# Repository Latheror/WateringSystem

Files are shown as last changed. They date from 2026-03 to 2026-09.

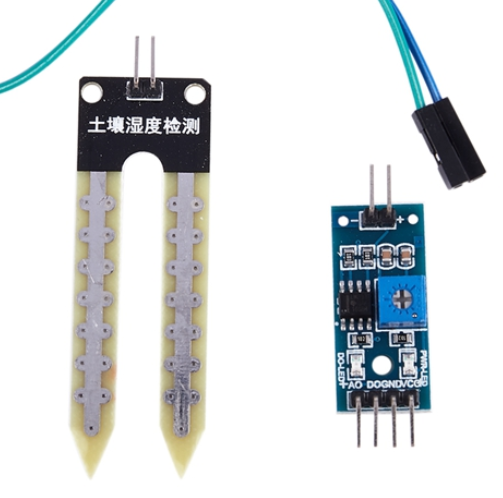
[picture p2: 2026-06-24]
Hardware/HygrometrySensor/HygrometrySensor.png

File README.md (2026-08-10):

# Watering System Project

## Overview
This project is an automated watering system for plants, featuring soil moisture monitoring, solar power management, and manual/automatic watering controls.

## Features
- **Soil Moisture Monitoring**: Real-time monitoring of soil moisture using both analog and digital sensors.
- **Automatic Watering**: Automatically activates the pump when soil moisture levels fall below a certain threshold.
- **Manual Watering**: Allows users to manually trigger a 10-second watering cycle via a web dashboard.
- **Power Management**: Monitors solar panel voltage and battery levels.
- **Web Dashboard**: A responsive web interface to view system status and control watering.

## Development Guidelines & Best Practices

### 1. Code Structure & Organization
- **Modularity**: Keep logic separated into different files (e.g., `wifi_handler.cpp`, `settings.h`).
- **Constants**: Use `settings.h` and `settings_user.h` for all hardware-specific configurations (pins, thresholds, WiFi credentials).
- **Non-blocking Code**: Avoid using `delay()` in the main loop where possible. Use `millis()` for timing-based operations (e.g., watering duration).

### 2. Hardware Abstraction
- **Relay Control**: Abstract relay operations to ensure consistent behavior (e.g., handling active-high vs. active-low modules).
- **Sensor Reading**: Standardize how sensors are read and processed before being used in logic.

### 3. Error Handling & Logging
- **Serial Debugging**: Use `Serial.println()` for critical state changes and errors.
- **Robustness**: Ensure the system can recover from WiFi disconnections or sensor failures.

### 4. Embedded C Best Practices
- **Memory Management**: Avoid dynamic memory allocation (`malloc`, `new`) to prevent memory fragmentation and leaks.
- **Data Types**: Use appropriate fixed-width integer types (e.g., `uint8_t`, `int32_t`) from `<stdint.h>`.
- **Naming Conventions**: Use clear, descriptive names for variables and functions.

## Project Structure
- `Board/`: Hardware design files.
- `Case/`: 3D model files for the enclosure.
- `Hardware/`: Component details and wiring diagrams.
- `system/`: Source code for the ESP32C3 microcontroller.

## PCB

The KiCad design files for the watering system are located in `PCB/`. These files are read and edited with KiCad 10.

### Design files

- `PCB/WateringSystem_PCB/WateringSystem_PCB.kicad_pro`: KiCad project file. It stores the KiCad project configuration and references the schematic and PCB layout.
- `PCB/WateringSystem_PCB/WateringSystem_PCB.kicad_sch`: KiCad schematic file. It describes the components, symbols, power rails, nets, and logical connections.
- `PCB/WateringSystem_PCB/WateringSystem_PCB.kicad_pcb`: KiCad PCB board file. It contains the board outline, footprints, copper tracks, vias, zones, and silkscreen.
- `PCB/WateringSystem_PCB/fp-lib-table`: KiCad footprint-library table. It tells KiCad where to find the custom and external footprint libraries used by the board.

### Custom libraries

- `PCB/ESP32-C3_SuperMini.kicad_sym`: Custom KiCad symbol-library file containing the ESP32-C3 SuperMini symbol used by the schematic.
- `PCB/General.kicad_sym`: Custom KiCad symbol-library file containing additional project-specific schematic symbols.
- `PCB/WateringSystem_PCB/ESP32-C3_SuperMini.pretty/ESP32-C3_SuperMini.kicad_mod`: Custom KiCad footprint file for the ESP32-C3 SuperMini module.

### Konnect configuration

- `PCB/WateringSystem_PCB/.konnect/project.json`: Project-specific KiCad/Konnect configuration, including design rules and fabrication preferences. Keep it versioned when those shared project settings are expected to be reproducible.

Generated Gerbers, drill files, ERC reports, backups, lock files, KiCad local preferences, and history files are intentionally excluded by `.gitignore`. They can be regenerated from the versioned design sources when needed.

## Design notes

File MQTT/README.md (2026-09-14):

# MQTT deployment

This directory is the single source of truth for the EMQX development and production broker deployment.

## Local setup

1. Copy `.env.example` to `.env`.
2. Set the MQTT and dashboard credentials locally. Do not commit `.env`.
3. Run `powershell -File scripts/broker.ps1 start`.
4. Check the broker with `powershell -File scripts/broker.ps1 status`.
5. Install MQTTX CLI once with `npm install --global mqttx-cli` for the
	authenticated publish/subscribe test.

The pinned image is `emqx/emqx:6.3.0`. MQTT is exposed on port `1883` and the dashboard on port `18083`. The setup uses EMQX's built-in password database, bootstrapped from an ignored runtime CSV generated from `.env`.

## Raspberry Pi setup

The Raspberry Pi must run 64-bit Raspberry Pi OS and report `aarch64` before deployment. Copy this directory, including the local `.env` and generated runtime bootstrap file, to the Pi without committing either file. Run `sh scripts/broker.sh start` from this directory.

The same image, credentials, topics, ports, and Compose configuration are used on both systems. MQTT remains limited to the trusted local network and is unencrypted in this first version.

## Operations

- `start`: prepare authentication data and start EMQX.
- `stop`: stop and remove the Compose container while keeping volumes.
- `restart`: restart the service.
- `status`: show Compose service status.
- `logs`: show the latest EMQX logs.
- `test`: prepare and start the service for the authenticated publish/subscribe test task.

Automated JSON publish checks use MQTTX CLI (`mqttx pub`). Mosquitto is not
required or used by this project. The payload is published with the retained
flag so an MQTTX subscriber that connects afterward receives it.

The state test publishes `examples/state-message.json` to `watering/state`:

```powershell
powershell -File scripts/test.ps1 -Topic watering/state -MessageFile examples/state-message.json
```

The command test publishes `examples/command-message.json` to
`watering/commands`:

```powershell
powershell -File scripts/test.ps1 -Topic watering/commands -MessageFile examples/command-message.json
```

Both payloads use the formats expected by the ESP32 firmware.

Passwords are never printed by the scripts.

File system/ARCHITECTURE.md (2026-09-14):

# Watering System Architecture

This document describes the architecture and runtime behavior of the ESP32-C3
watering system.

## System Overview

The device monitors soil moisture and power conditions, controls a water pump,
and exposes a web dashboard for monitoring and manual control. The watering
state machine drives the pump; the physical button only controls temporary
status-LED visibility, to conserve battery.

## Core Components

### Sensors

- `SoilMoistureSensor`: Measures soil moisture and classifies it as `DRY`,
  `WET`, or `FLOATING`. `FLOATING` indicates a disconnected or invalid
  reading and is treated as a safety state (see below).
- `VoltageSensor`: Measures solar-panel voltage.
- `Battery`: Measures battery voltage and evaluates the low-battery condition.

### Inputs

- `Button`: Detects when the physical button is held down. Held state
  enables status-LED visibility for as long as it is held; it has no effect
  on watering.

### Outputs

- `PumpHandler`: Controls the water pump through the relay.
- `Led`: Controls four status indicators — Wi-Fi, pump, battery, and
  automatic-mode — as described in [Status LEDs](#status-leds).

### Connectivity

- `WiFiReconnector`: Maintains the Wi-Fi connection with automatic retries
  and exponential backoff.

## Operating Modes

The system operates in one of two modes, toggled from the web dashboard:

- **Automatic mode**: the watering state machine may start watering on its
  own when the automatic conditions are met.
- **Manual mode**: automatic watering is disabled. The user can force a
  watering cycle via a "water now" control on the web dashboard.

## Watering State Machine

The main control logic is implemented in `system.ino`.

- **Automatic watering** starts when all of the following hold:
    - the system is in automatic mode,
    - the soil reading is `DRY` (not `WET`, and not `FLOATING` — a
      `FLOATING` reading is treated as a safety condition and never triggers
      watering),
    - the automatic-watering wait period has elapsed,
    - the battery is above the pump safety threshold.
- **Manual watering** starts on request from the web dashboard while in
  manual mode, and **bypasses all other conditions** (battery threshold,
  automatic-watering wait period, soil reading).
- **Watering cycle**: once started, the pump stays active for the configured
  duration, or until battery protection interrupts it.
- **Battery protection**: stops an *automatic* cycle early if the battery
  drops too low. Manual cycles are not subject to this check.
- **Automatic-watering wait period**: after any automatic watering cycle, prevents another
  automatic cycle from starting until the configured interval has elapsed.
  Does not apply to manual watering.

## Status LEDs

There are four status LEDs, one per boolean system state: Wi-Fi connected,
pump active, battery low, and automatic mode enabled.

Each LED reflects its associated state, but is only physically lit while the
button is currently held down; as soon as the state is true **and** the
button is pressed, the LED turns on, and it turns off immediately on
release, regardless of the underlying state. This keeps the LEDs off by
default to conserve battery.

## Web Interface

The embedded web server provides:

- Real-time soil, solar-voltage, battery-voltage, pump, and mode
  information.
- A control to toggle between automatic and manual mode.
- A control to request manual watering (active only in manual mode).
- Periodic page updates for near-real-time status.

## MQTT Commands and Deep Sleep

MQTT commands are handled through `onMqttCommand()`. The requested automatic
mode is applied immediately, while a manual watering request is queued for the
main-loop watering state machine. This keeps pump control in one execution path
and allows manual watering to follow its documented override behavior.

After the wake cycle has run for at least 30 seconds and no watering cycle is
active, the main loop forces the pump off, accounts for the upcoming sleep in
the persisted automatic-watering cooldown, and enters timed deep sleep. The
timer wakes the ESP32 after five minutes. MQTT or Wi-Fi connectivity does not
extend this deadline.

## Runtime Data Flow

1. The main loop reads the soil sensor, voltage sensors, button state, and
   Wi-Fi state, while the web server processes incoming requests.
2. The watering state machine evaluates the current mode, automatic
  conditions (soil, battery, automatic-watering wait period), and any pending manual request.
3. The firmware drives the pump according to the watering state.
4. The firmware drives the status LEDs according to system state, gated by
   whether the button is currently held.
5. The latest sensor readings and system state are published through the
   web dashboard.

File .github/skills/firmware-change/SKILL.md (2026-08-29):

---
name: firmware-change
description: Use when implementing or reviewing a WateringSystem ESP32-C3 firmware change involving sensors, watering logic, pump control, LEDs, Wi-Fi, web routes, timing, or settings.
---

# Firmware change workflow

1. Read `system/ARCHITECTURE.md`, the target module, and its header before editing.
2. Identify the behavioral contract: inputs, outputs, timing, safety conditions, and whether the path is automatic or manual.
3. Make the smallest change that preserves existing module boundaries and configuration constants.
4. Check for edge cases involving invalid sensor readings, low battery, Wi-Fi loss, button release, repeated requests, and `millis()` rollover.
5. Update `system/ARCHITECTURE.md` if the externally visible behavior or safety policy changed.
6. Run the `Build Firmware` VS Code task to compile without uploading. Use the direct `arduino-cli` command only if the task runner is unavailable.

7. Report the changed files, compile result, and what still requires testing on real hardware.

Never upload firmware as part of this workflow unless the user explicitly requests flashing.

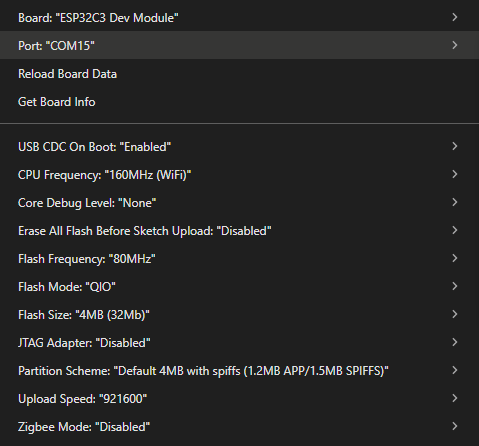
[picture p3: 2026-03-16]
Board/ArduinoSettings.png

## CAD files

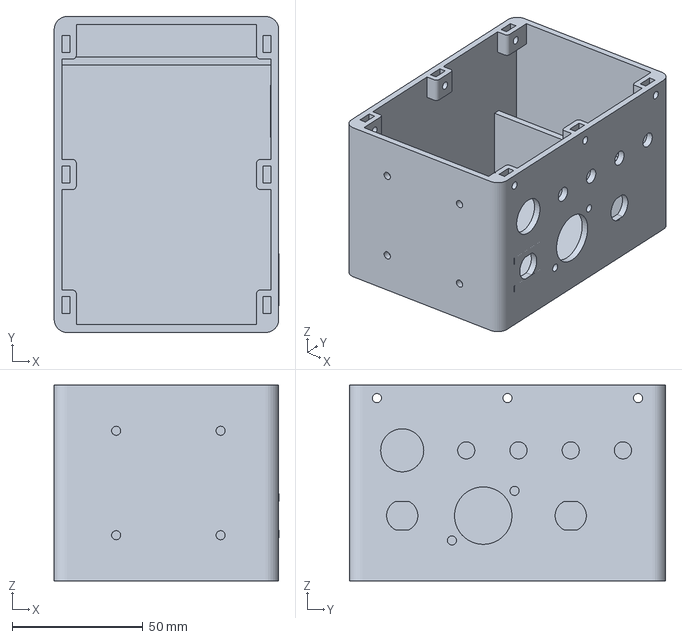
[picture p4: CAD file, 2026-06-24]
Case/WateringSystem_Bottom.3mf
86.0 x 121.0 x 75.0 mm

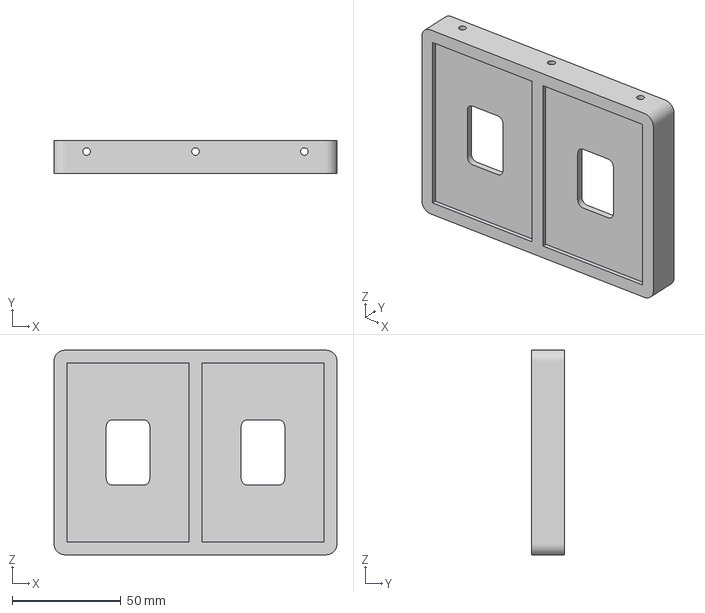
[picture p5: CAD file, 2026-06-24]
Case/WateringSystem.3mf
130.0 x 15.0 x 94.0 mm

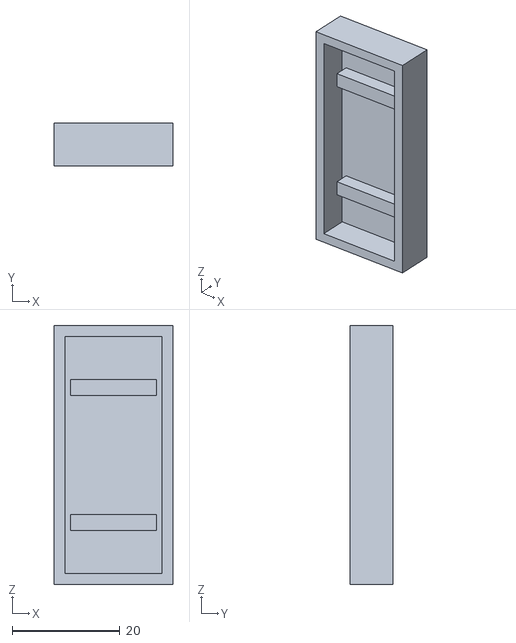
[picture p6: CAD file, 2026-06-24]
Case/RelaySupport.stl
22.0 x 8.00 x 48.0

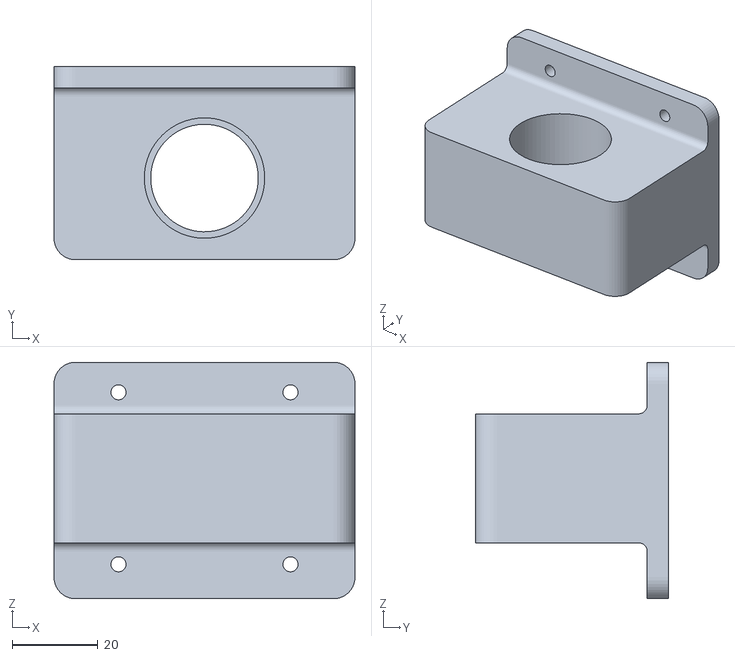
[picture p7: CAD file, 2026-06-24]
Case/PumpSupport.stl
70.0 x 45.0 x 55.0

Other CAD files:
Case/WateringSystem_Bottom.f3d
Case/WateringSystem_Bottom.stl

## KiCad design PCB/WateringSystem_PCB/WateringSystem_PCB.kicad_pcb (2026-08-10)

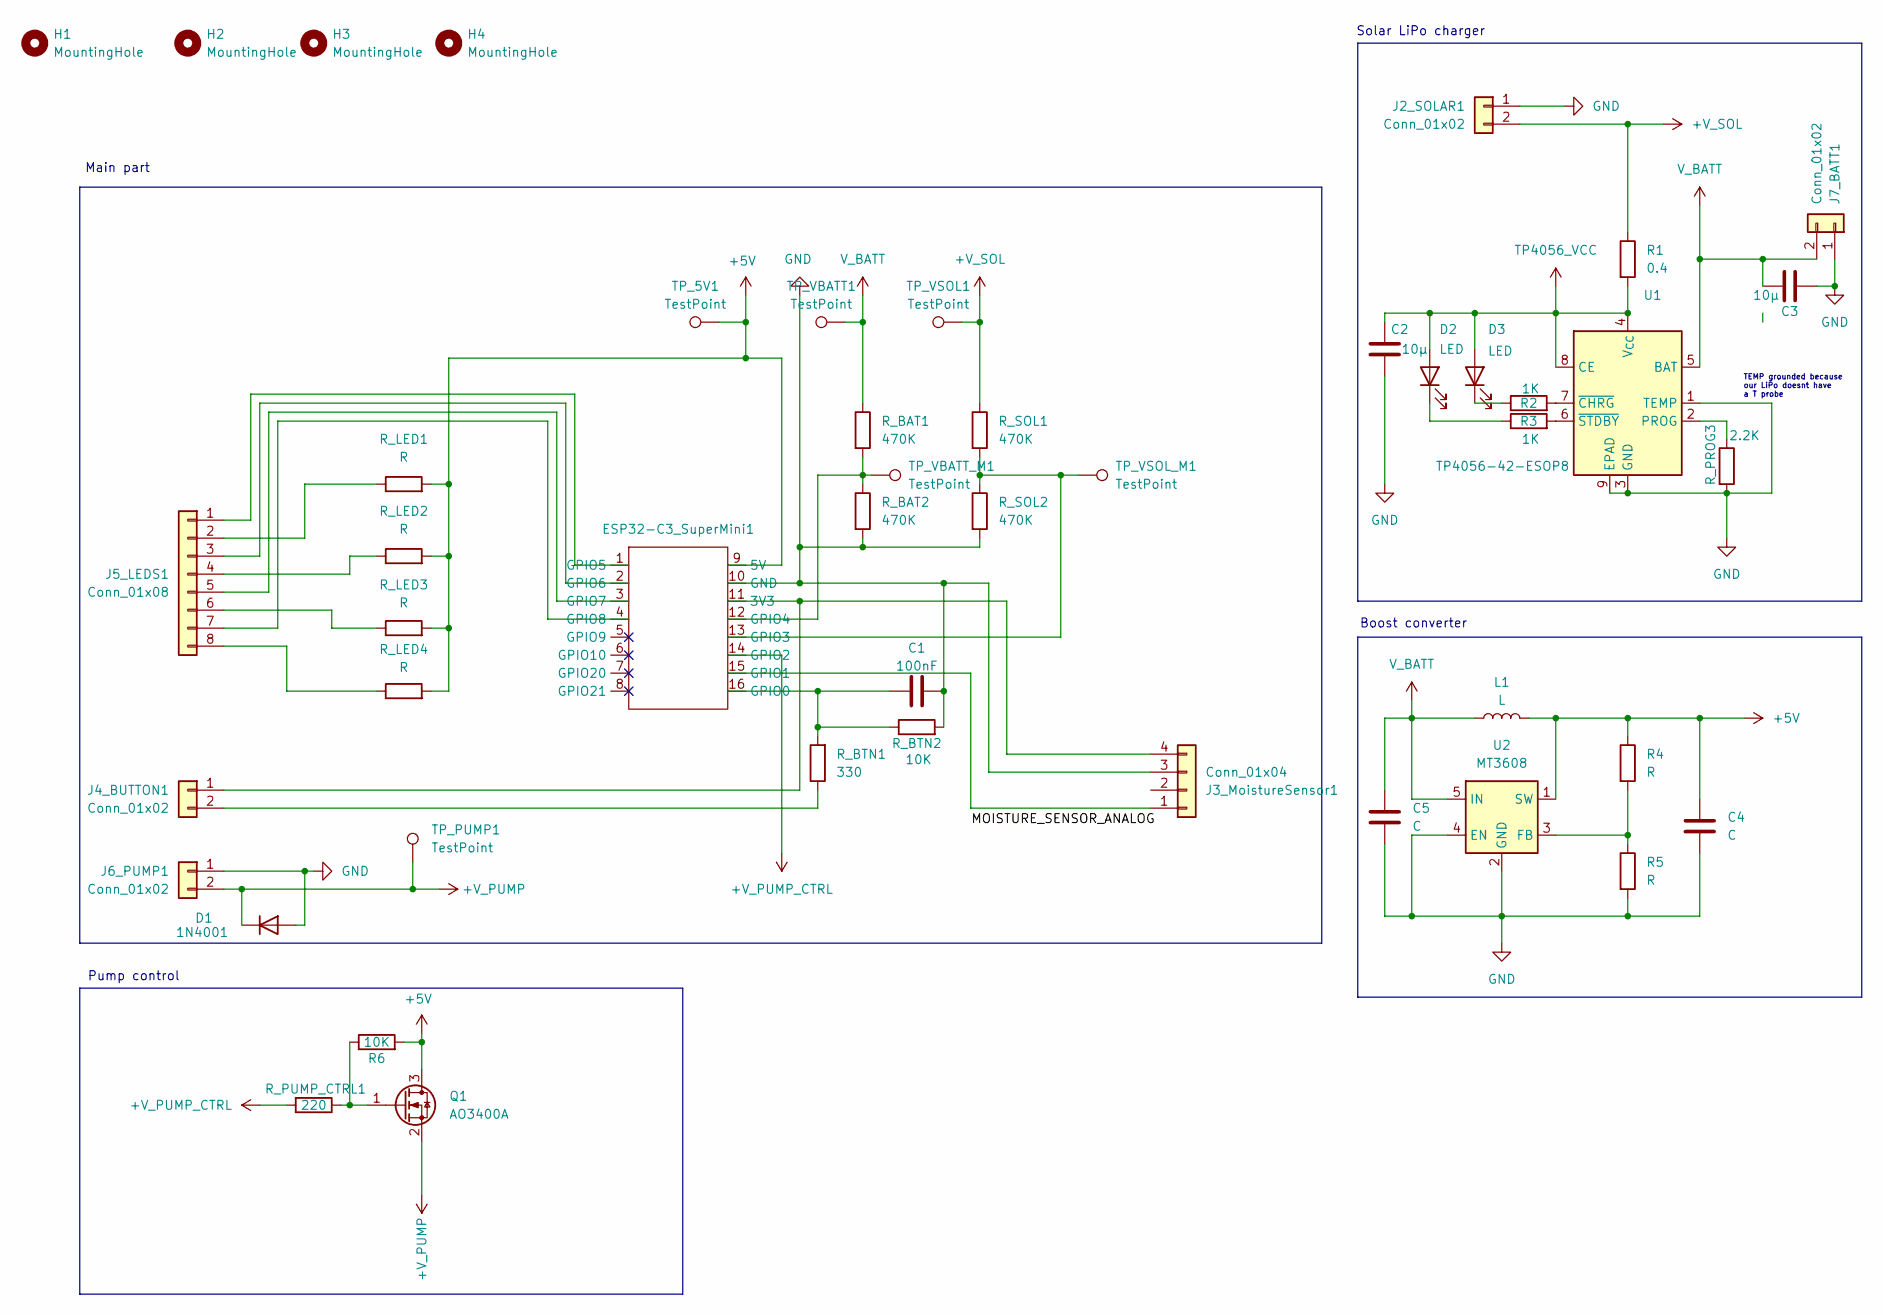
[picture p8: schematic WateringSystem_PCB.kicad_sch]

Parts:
C1: 100nF; CP_Radial_D4.0mm_P1.50mm
C2, C3: 10µ; C_1206_3216Metric_Pad1.33x1.80mm_HandSolder
C4, C5: C; C_1206_3216Metric_Pad1.33x1.80mm_HandSolder
D1: 1N4001; D_DO-41_SOD81_P10.16mm_Horizontal
D2, D3: LED; LED_1206_3216Metric_Pad1.42x1.75mm_HandSolder
ESP32-C3_SuperMini1: ESP32-C3_SuperMini
H1, H2, H3, H4: MountingHole; MountingHole_3.2mm_M3
J2_SOLAR1, J4_BUTTON1, J6_PUMP1, J7_BATT1: Conn_01x02; JST_XH_B2B-XH-A_1x02_P2.50mm_Vertical
J3_MoistureSensor1: Conn_01x04; JST_XH_B4B-XH-A_1x04_P2.50mm_Vertical
J5_LEDS1: Conn_01x08; JST_XH_B8B-XH-A_1x08_P2.50mm_Vertical
L1: L; L_Coilcraft_LPS4018
Q1: AO3400A; SOT-23
R1: 0.4; R_1206_3216Metric_Pad1.30x1.75mm_HandSolder
R2, R3: 1K; R_1206_3216Metric_Pad1.30x1.75mm_HandSolder
R4, R5: R; R_1206_3216Metric_Pad1.30x1.75mm_HandSolder
R6: 10K; R_1206_3216Metric_Pad1.30x1.75mm_HandSolder
R_BAT1, R_BAT2: 470K; R_1206_3216Metric_Pad1.30x1.75mm_HandSolder
R_BTN1: 330; R_1206_3216Metric_Pad1.30x1.75mm_HandSolder
R_BTN2: 10K; R_1206_3216Metric_Pad1.30x1.75mm_HandSolder
R_LED1, R_LED2, R_LED3, R_LED4: R; R_1206_3216Metric_Pad1.30x1.75mm_HandSolder
R_PROG3: 2.2K; R_1206_3216Metric_Pad1.30x1.75mm_HandSolder
R_PUMP_CTRL1: 220; R_1206_3216Metric_Pad1.30x1.75mm_HandSolder
R_SOL1, R_SOL2: 470K; R_1206_3216Metric_Pad1.30x1.75mm_HandSolder
TP_5V1: TestPoint; TestPoint_Pad_1.0x1.0mm
TP_PUMP1: TestPoint; TestPoint_Pad_1.0x1.0mm
TP_VBATT1: TestPoint; TestPoint_Pad_1.0x1.0mm
TP_VBATT_M1: TestPoint; TestPoint_Pad_1.0x1.0mm
TP_VSOL1: TestPoint; TestPoint_Pad_1.0x1.0mm
TP_VSOL_M1: TestPoint; TestPoint_Pad_1.0x1.0mm
U1: TP4056-42-ESOP8; SOIC-8-1EP_3.9x4.9mm_P1.27mm_EP2.29x3mm
U2: MT3608; SOT-23-6

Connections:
+5V: C4.1, ESP32-C3_SuperMini1.9 (5V), L1.2, Q1.3 (D), R4.1, R6.2, R_LED1.2, R_LED2.2, R_LED3.2, R_LED4.2, TP_5V1.1 (1_1), U2.1 (SW)
+V_PUMP: D1.1 (K), J6_PUMP1.2, Q1.2 (S), TP_PUMP1.1 (1_1)
+V_PUMP_CTRL: ESP32-C3_SuperMini1.14 (GPIO2), R_PUMP_CTRL1.2
+V_SOL: J2_SOLAR1.2, R1.1, R_SOL1.1, TP_VSOL1.1 (1_1)
GND: C1.2, C2.2, C3.2, C4.2, C5.2, D1.2 (A), ESP32-C3_SuperMini1.10 (GND), J2_SOLAR1.1, J3_MoistureSensor1.3, J6_PUMP1.1, J7_BATT1.1, R5.2, R_BAT2.2, R_BTN2.2, R_PROG3.2, R_SOL2.2, U1.1 (TEMP), U1.3 (GND), U1.9 (EPAD), U2.2 (GND), U2.4 (EN)
unnamed: D2.1 (K), R3.1
unnamed: D3.1 (K), R2.1
unnamed: ESP32-C3_SuperMini1.11 (3V3), J3_MoistureSensor1.4, J4_BUTTON1.1
unnamed: C1.1, ESP32-C3_SuperMini1.16 (GPIO0), R_BTN1.2, R_BTN2.1
unnamed: ESP32-C3_SuperMini1.15 (GPIO1), J3_MoistureSensor1.1
unnamed: ESP32-C3_SuperMini1.13 (GPIO3), R_SOL1.2, R_SOL2.1, TP_VSOL_M1.1 (1_1)
unnamed: ESP32-C3_SuperMini1.12 (GPIO4), R_BAT1.2, R_BAT2.1, TP_VBATT_M1.1 (1_1)
unnamed: ESP32-C3_SuperMini1.1 (GPIO5), J5_LEDS1.1
unnamed: ESP32-C3_SuperMini1.2 (GPIO6), J5_LEDS1.3
unnamed: ESP32-C3_SuperMini1.3 (GPIO7), J5_LEDS1.5
unnamed: ESP32-C3_SuperMini1.4 (GPIO8), J5_LEDS1.7
unnamed: J4_BUTTON1.2, R_BTN1.1
unnamed: J5_LEDS1.2, R_LED1.1
unnamed: J5_LEDS1.4, R_LED2.1
unnamed: J5_LEDS1.6, R_LED3.1
unnamed: J5_LEDS1.8, R_LED4.1
unnamed: Q1.1 (G), R6.1, R_PUMP_CTRL1.1
unnamed: R_PROG3.1, U1.2 (PROG)
unnamed: R2.2, U1.7 (~CHRG)
unnamed: R3.2, U1.6 (~STDBY)
unnamed: R4.2, R5.1, U2.3 (FB)
TP4056_VCC: C2.1, D2.2 (A), D3.2 (A), R1.2, U1.4 (V_{CC}), U1.8 (CE)
V_BATT: C3.1, C5.1, J7_BATT1.2, L1.1, R_BAT1.1, TP_VBATT1.1 (1_1), U1.5 (BAT), U2.5 (IN)

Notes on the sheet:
Boost converter
Solar LiPo charger
Pump control
Main part
TEMP grounded because our LiPo doesnt have a T probe

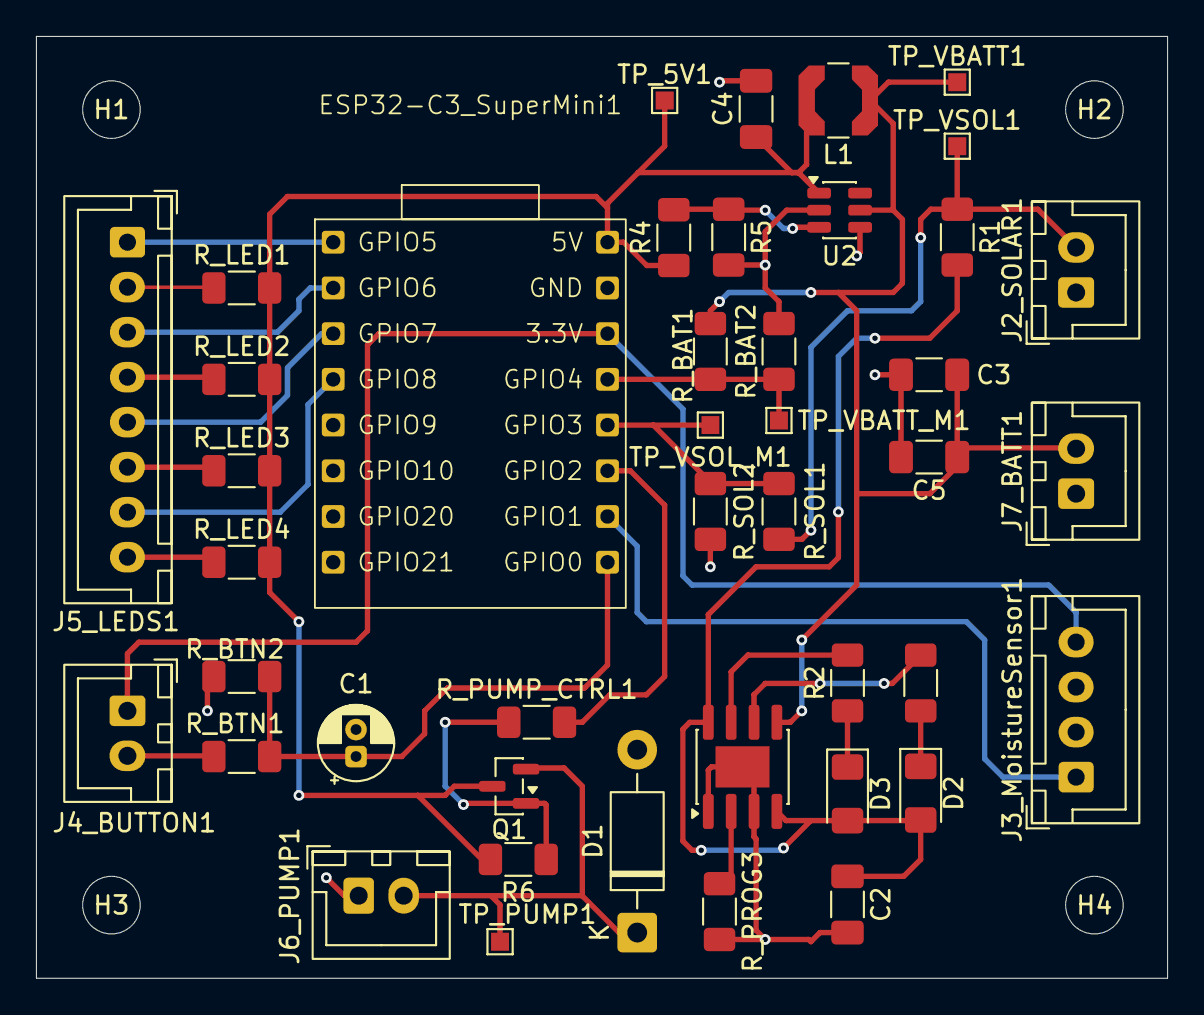
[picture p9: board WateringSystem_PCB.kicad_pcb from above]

Board: 2 copper layers, 62.8 x 52.3 mm, 47 parts (0 on the bottom side), 28 nets.

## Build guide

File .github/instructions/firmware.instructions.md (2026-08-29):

---
name: WateringSystem firmware conventions
description: Apply when editing Arduino, C++, or header files in the ESP32-C3 firmware.
applyTo: "system/**/*.{ino,cpp,h}"
---

# Firmware conventions

- Keep each module's implementation in its matching `.cpp` file and declarations in its matching `.h` file.
- Use the existing class and function names unless an API change is necessary.
- Include `settings.h` for project configuration rather than duplicating pin numbers or timing constants.
- Use fixed-width integer types where a width matters, and use `uint32_t` for millisecond timestamps.
- Handle `millis()` rollover-safe comparisons with unsigned subtraction.
- Keep `loop()` responsive: do not add blocking waits for sensor reads, Wi-Fi retries, pump cycles, or web requests.
- Preserve the distinction between automatic and manual watering. Manual watering may bypass automatic conditions only where the existing architecture specifies it.
- Treat invalid, floating, or disconnected sensor readings as safe inputs; never turn them into an automatic watering request.
- Avoid logging secrets and avoid adding verbose serial output to battery-sensitive paths.
- Update `ARCHITECTURE.md` when a user-visible state transition or safety rule changes.

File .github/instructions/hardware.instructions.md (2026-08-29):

---
name: WateringSystem hardware constraints
description: Apply when editing KiCad files, hardware documentation, pin mappings, sensor calibration, or electrical behavior.
applyTo: "{PCB/**/*.kicad_*,PCB/**/*.kicad_sym,PCB/**/*.kicad_mod,Hardware/**/*,Board/**/*,system/settings.h,system/*sensor*,system/battery.*}"
---

# Hardware constraints

- Treat the schematic and PCB as the source of truth for connectivity and pin usage.
- Before changing a GPIO, verify the corresponding schematic net, PCB pad, board variant, and ESP32-C3 boot implications.
- Before changing an ADC conversion or threshold, verify the resistor-divider values, expected voltage range, ADC attenuation/configuration, and sensor wiring.
- Check relay active level and power-path behavior before changing pump control logic.
- For KiCad changes, preserve project-library references and run the appropriate ERC/DRC or connectivity check when available.
- Do not claim hardware validation from compilation alone. Clearly separate source-level validation from bench testing.
- Never place Wi-Fi credentials or other secrets in hardware documentation or generated reports.

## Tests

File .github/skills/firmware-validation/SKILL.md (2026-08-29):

---
name: firmware-validation
description: Use when validating, compiling, preparing to flash, or investigating a WateringSystem ESP32-C3 firmware build.
---

# Firmware validation workflow

## Source validation

Run the `Build Firmware` VS Code task. It compiles the ESP32-C3 firmware without uploading. Use the direct `arduino-cli` compile command only as a fallback when VS Code tasks cannot be run.

Then inspect the diff for accidental GPIO, timing, polarity, credential, or generated-file changes.

## Device validation

Only flash after the user confirms deployment. Run the repository `Build & Flash Firmware` task, which owns the board, upload speed, port, and project path. Do not duplicate those task details in new instructions or documentation.

After flashing, validate at minimum:

- Wi-Fi connection and reconnect behavior.
- Soil readings, including disconnected/floating sensor behavior.
- Automatic watering start, duration, cooldown, and low-battery interruption.
- Manual watering mode and its intended safety behavior.
- Pump relay polarity and status LEDs while holding/releasing the button.
- Web dashboard state and controls.

Do not report a successful bench test when only compilation was performed. Do not include credentials in logs or reports.

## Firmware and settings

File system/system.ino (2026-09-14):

#include <Arduino.h>

#include "settings.h"
#include "wifi_handler.h"
#include "mqtt_handler.h"
#include "pump_handler.h"
#include "soil_moisture_sensor.h"
#include "voltage_sensor.h"
#include "battery.h"
#include "led.h"
#include "button.h"
#include "persistence.h"
#include "deepsleep.h"

// =========================
// WIFI
// =========================
WiFiReconnector wifiReconnector(WIFI_SSID, WIFI_PASS);

// =========================
// SENSORS
// =========================
SoilMoistureSensor soilSensor(SOIL_MOISTURE_SENSOR_ANALOG_PIN);

VoltageSensor solarSensor(
    SOLAR_VOLTAGE_PIN,
    3.3f,
    4095,
    (SOLAR_DIVIDER_R1 + SOLAR_DIVIDER_R2) / SOLAR_DIVIDER_R1);

Battery battery;

// =========================
// SYSTEM STATE
// =========================
bool manualRequestPending = false;
bool manualMode = false;
bool pumpActive = false;
bool shouldWater = false;
bool autoMode = true;

bool wateringActive = false;
bool wasWifiConnected = false;
bool statePublishedForConnection = false;
unsigned long lastMqttAttemptTime = 0;
unsigned long wakeCycleStartTime = 0;
unsigned long lastWateringTickTime = 0;
bool wakeCycleEvaluated = false;

// Latest coherent sample published by the MQTT state publisher.
float solarVoltage = 0.0f;
float batteryVoltage = 0.0f;
float soilMoisture = 0.0f;
SoilStatus soilStatus = SoilStatus::UNKNOWN;

unsigned long lastWateringStartTime =
    (unsigned long)(0 - AUTO_WATERING_INTERVAL_MS);

// Countdown until another automatic watering window may begin.
unsigned long remainingWateringWaitingTimeMs = 0;

// =========================
// INPUT EVENT HANDLER
// =========================

/**
 * Marks a manual watering request for processing by updateWateringState().
 * The request is deferred so the MQTT callback does not start the pump while
 * the main loop is handling network traffic.
 */
void onManualWateringRequest() {
    manualRequestPending = true;
}

/**
 * Applies an MQTT command to the watering controller.
 *
 * The requested mode takes effect immediately. A manual watering request is
 * queued for the next watering-state update, where it is consumed and may
 * bypass automatic watering conditions as defined by the state machine.
 *
 * @param requestedAutoMode Whether automatic watering should be enabled.
 * @param manualWatering   Whether a manual watering cycle was requested.
 */
void onMqttCommand(bool requestedAutoMode, bool manualWatering) {
    autoMode = requestedAutoMode;
    if (manualWatering) {
        onManualWateringRequest();
    }
}

/**
 * Completes the current wake cycle and enters timed deep sleep.
 *
 * The pump is forced off before the sleep interval is prepared. The
 * automatic-watering cooldown is adjusted for the sleep period and retained
 * across deep sleep before the ESP32 enters its timer wake.
 */
void prepareAndEnterDeepSleep() {
    setPumpState(false);

    const uint32_t sleepDurationMs = DEEP_SLEEP_WAKE_INTERVAL_SECONDS * 1000UL;
    prepareWateringWaitingTimeForDeepSleep(sleepDurationMs);
    enterDeepSleep();
}

// =========================
// HELPERS
// =========================

/**
 * Reads the soil moisture, solar voltage, and battery voltage sensors,
 * and logs a compact one-line summary to Serial.
 *
 * @param[out] soilMoisture         Soil moisture reading, in percent.
 * @param[out] soilStatus           Classified soil status (DRY/WET/FLOATING).
 * @param[out] solarVoltageReading  Solar panel voltage, in volts.
 * @param[out] batteryVoltageReading Battery voltage, in volts.
 */
void readAndLogSensors(float &soilMoisture, SoilStatus &soilStatus,
                        float &solarVoltageReading,
                        float &batteryVoltageReading) {
    soilMoisture = soilSensor.read();
    soilStatus = soilSensor.getSoilStatus();

    solarVoltageReading = solarSensor.read();
    batteryVoltageReading = battery.read();

    const char *soilStatusStr = "UNKNOWN";
    switch (soilStatus) {
        case SoilStatus::DRY:      soilStatusStr = "DRY";      break;
        case SoilStatus::WET:      soilStatusStr = "WET";      break;
        case SoilStatus::FLOATING: soilStatusStr = "FLOATING"; break;
        default: break;
    }

    Serial.printf(
        "Battery: %.2fV | Solar: %.2fV | Soil: %.1f%% (%s)\n",
        batteryVoltageReading, solarVoltageReading, soilMoisture,
        soilStatusStr);
}

/**
 * Advances the watering state machine by one tick.
 *
 * Starts a new watering cycle if either a manual request is pending, or
 * the soil is dry and the watering wait time has elapsed.
 * Ends the cycle once AUTO_WATERING_DURATION_MS has passed. Manual watering
 * is allowed even when the battery is low.
 *
 * @param currentTime Current time, in milliseconds (from millis()).
 * @param soilIsDry   Whether the soil sensor currently reports DRY.
 * @param batteryLow  Whether the battery is below the pump safety threshold.
 * @return true if the pump should be ON right now, false otherwise.
 */
bool updateWateringState(unsigned long currentTime, bool soilIsDry,
                         bool batteryLow) {
    unsigned long elapsedSinceStart = currentTime - lastWateringStartTime;
    unsigned long elapsedSinceTick = currentTime - lastWateringTickTime;
    lastWateringTickTime = currentTime;

    advanceWateringWaitingTime(elapsedSinceTick);
    remainingWateringWaitingTimeMs = getRemainingWateringWaitingTimeMs();

    // Low battery stops automatic watering, but not manual watering.
    if (batteryLow && wateringActive && !manualMode) {
        wateringActive = false;
        Serial.println("Watering stopped: battery too low");
        return false;
    }

    // Try to start a new watering cycle
    if (!wateringActive) {
        bool wateringWaitFinished = getRemainingWateringWaitingTimeMs() == 0;

        // Manual requests are intentional overrides and bypass the wait time.
        bool canStartManual = manualRequestPending;
        bool canStartAuto = autoMode && soilIsDry && wateringWaitFinished && !batteryLow;

        if (canStartManual ||
            (canStartAuto && isWateringWaitingTimePersistenceHealthy())) {
            if (canStartAuto) {
                if (!startAutomaticWateringWaitingTime(AUTO_WATERING_INTERVAL_MS)) {
                    return false;
                }
            }
            wateringActive = true;
            manualMode = canStartManual;
            manualRequestPending = false;

            lastWateringStartTime = currentTime;
            elapsedSinceStart = 0;

            Serial.println(manualMode
                                ? "Manual watering started"
                                : "Automatic watering started");
        }
    }

    // Run / finish the active watering window
    if (wateringActive) {
        if (elapsedSinceStart < AUTO_WATERING_DURATION_MS) {
            remainingWateringWaitingTimeMs = 0;
            return true;
        }

        wateringActive = false;
        manualMode = false;
        Serial.println("Watering window finished");
    }

    // Update the remaining automatic-watering wait time.
    remainingWateringWaitingTimeMs =
        (elapsedSinceStart < AUTO_WATERING_INTERVAL_MS)
            ? (AUTO_WATERING_INTERVAL_MS - elapsedSinceStart)
            : 0;

    return false;
}

/**
 * Arduino setup(). Initializes serial, pins, LEDs, the button, and WiFi.
 * Runs once on boot.
 */
void setup() {
    Serial.begin(115200);
    Serial.println("Start");

    // Drive the active-low relay to its safe state before enabling the output.
    digitalWrite(RELAY_PIN, HIGH);
    pinMode(RELAY_PIN, OUTPUT);
    pinMode(SOLAR_VOLTAGE_PIN, INPUT);
    battery.begin();

    setPumpState(false);

    initLeds();
    initButton();
    initMqtt(onMqttCommand);
    initWateringWaitingTimePersistence();

    bool wifiOk = wifiReconnector.begin();
    wakeCycleStartTime = millis();
    lastWateringTickTime = wakeCycleStartTime;
    setWifiLed(wifiOk);
}

/**
 * Arduino loop(). Reads inputs (button, WiFi, sensors), updates the
 * watering state machine, and drives outputs (pump, LEDs, relay).
 */
void loop() {
    // -------------------------
    // Button
    // -------------------------
    bool buttonPressed = isButtonPressed();

    // -------------------------
    // WiFi
    // -------------------------
    wifiReconnector.handle();
    bool wifiConnected = wifiReconnector.isConnected();
    bool wifiJustConnected = wifiConnected && !wasWifiConnected;

    if (wifiJustConnected) {
        WiFi.setSleep(true);
    }
    wasWifiConnected = wifiConnected;

    unsigned long currentTime = millis();
    if (wifiConnected && !isMqttConnected() &&
        (currentTime - wakeCycleStartTime < MQTT_WAKE_CYCLE_DEADLINE_MS ||
         wifiJustConnected) &&
        currentTime - lastMqttAttemptTime >= MQTT_CONNECTION_TIMEOUT_MS) {
        lastMqttAttemptTime = currentTime;
        Serial.println("[MQTT] Connection attempt started");
        if (connectMqtt()) {
            Serial.println("[MQTT] Connected and subscribed");
            statePublishedForConnection = false;
        } else {
            Serial.println("[MQTT] Connection attempt failed");
        }
    }
    handleMqtt();

    // Status LEDs are only visible while the button is held.
    setWifiLed(wifiConnected && buttonPressed);
    setAutoModeLed(autoMode && buttonPressed);

    // -------------------------
    // Sensors
    // -------------------------
    float soilMoistureReading, solarVoltageReading, batteryVoltageReading;
    SoilStatus soilStatusReading;
    readAndLogSensors(soilMoistureReading, soilStatusReading, solarVoltageReading,
                       batteryVoltageReading);

    // Publish the same coherent sample that drives the controller and MQTT.
    soilMoisture = soilMoistureReading;
    soilStatus = soilStatusReading;
    solarVoltage = solarVoltageReading;
    batteryVoltage = batteryVoltageReading;

    bool batteryLow = battery.isLow(batteryVoltageReading);
    setBatteryLowLed(batteryLow && buttonPressed);

    // -------------------------
    // Watering control
    // -------------------------
    bool soilIsDry = (soilStatusReading == SoilStatus::DRY);

    shouldWater = updateWateringState(currentTime, soilIsDry, batteryLow);
    Serial.println(shouldWater ? "shouldWater: TRUE" : "shouldWater: FALSE");

    setPumpState(shouldWater);
    pumpActive = shouldWater;
    setPumpLed(pumpActive && buttonPressed);

    if (isMqttConnected() && !statePublishedForConnection) {
        statePublishedForConnection = publishMqttState(
            soilMoisture, soilStatus, solarVoltage, batteryVoltage,
            pumpActive, shouldWater, autoMode,
            remainingWateringWaitingTimeMs / 1000UL, batteryLow, wifiConnected);
    }

    wakeCycleEvaluated = true;
    if (wakeCycleEvaluated &&
        currentTime - wakeCycleStartTime >= MQTT_WAKE_CYCLE_DEADLINE_MS &&
        !wateringActive) {
        prepareAndEnterDeepSleep();
    }

    // -------------------------
    // Loop delay
    // -------------------------
    delay(LOOP_DELAY_MS);
}

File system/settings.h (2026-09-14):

#ifndef SETTINGS_H
#define SETTINGS_H

/**
 * @file settings.h
 * @brief Project-wide configuration constants for Watering System.
 */

#include "settings_user.h"

// =========================
// MQTT CONFIGURATION
// =========================

/**
 * @brief MQTT broker address and credentials are supplied by settings_user.h.
 */
#ifndef MQTT_BROKER_HOST
#define MQTT_BROKER_HOST ""
#endif

#ifndef MQTT_USERNAME
#define MQTT_USERNAME ""
#endif

#ifndef MQTT_PASSWORD
#define MQTT_PASSWORD ""
#endif

#define MQTT_BROKER_PORT              1883
#define MQTT_CLIENT_ID               "watering-device-01"
#define MQTT_STATE_TOPIC             "watering/state"
#define MQTT_COMMAND_TOPIC           "watering/commands"
#define MQTT_QOS                     1
#define MQTT_RETAIN_STATE            true
#define MQTT_KEEP_ALIVE_SECONDS      60
#define MQTT_CONNECTION_TIMEOUT_MS   5000
#define MQTT_WAKE_CYCLE_DEADLINE_MS  30000
#define MQTT_RETRY_LIMIT              2
#define MQTT_COMMAND_ID_MAX_LENGTH    63
#define DEEP_SLEEP_WAKE_INTERVAL_SECONDS (5 * 60)
#define FIRMWARE_VERSION             "1.0.0"

// =========================
// GPIO PIN ASSIGNMENTS
// =========================

/**
 * @brief GPIO pin connected to the push button.
 *        Button connects VCC to this pin. Internal pulldown enabled;
 *        add an external 10kΩ pulldown if unstable.
 */
#define BUTTON_PIN 0

/**
 * @brief GPIO pin controlling the relay module (pump/valve).
 */
#define RELAY_PIN 10


// =========================
// SOIL MOISTURE SENSOR CONFIGURATION
// =========================

/**
 * @brief Analog pin connected to the soil moisture sensor's analog output (AO).
 */
#define SOIL_MOISTURE_SENSOR_ANALOG_PIN 1

/**
 * @brief Soil moisture threshold (0-4095 ADC range).
 *        Values ABOVE this threshold = DRY, values BELOW = WET.
 */
#define SOIL_MOISTURE_THRESHOLD (4096 * 3 / 4)

/**
 * @brief Soil moisture floating threshold (0-4095 ADC range).
 *        Readings within this distance of the ADC maximum are FLOATING
 *        (sensor not in soil / disconnected / unreliable reading).
 */
#define SOIL_MOISTURE_FLOATING_THRESHOLD 100


// =========================
// SOLAR PANEL & BATTERY CONFIGURATION
// =========================

/**
 * @brief Analog pin for solar panel voltage.
 */
#define SOLAR_VOLTAGE_PIN 3

/**
 * @brief Analog pin for battery level.
 */
#define BATTERY_LEVEL_PIN 4

/**
 * @brief Resistor values for the solar panel voltage divider.
 *        Two 470k resistors are used.
 */
#define SOLAR_DIVIDER_R1 470000.0
#define SOLAR_DIVIDER_R2 470000.0

/**
 * @brief Resistor values for the battery voltage divider.
 *        Two 470k resistors are used.
 */
#define BATTERY_DIVIDER_R1 470000.0
#define BATTERY_DIVIDER_R2 470000.0


// =========================
// LED STATUS INDICATOR PINS
// =========================

#define LED_PIN_BATTERY_LOW    5
#define LED_PIN_AUTO_MODE      6
#define LED_PIN_PUMP_ACTIVE    7
#define LED_PIN_WIFI_CONNECTED 8

/**
 * @brief Battery voltage threshold for the low battery indicator.
 *        Values BELOW this threshold trigger the low battery LED.
 */
#define BATTERY_LOW_THRESHOLD 3.5f


// =========================
// WIFI AUTO-RECONNECT CONFIGURATION
// =========================

/**
 * @brief Base delay (ms) before the first WiFi reconnection attempt.
 *        Each subsequent retry doubles this value until WIFI_RETRY_MAX_DELAY_MS.
 */
#define WIFI_RETRY_BASE_DELAY_MS    10000  // 10 seconds

/**
 * @brief Maximum delay (ms) between WiFi reconnection attempts.
 */
#define WIFI_RETRY_MAX_DELAY_MS    600000  // 10 minutes


// =========================
// AUTOMATIC WATERING CONFIGURATION
// =========================

/**
 * @brief Duration (ms) the pump remains ON during automatic watering.
 */
#define AUTO_WATERING_DURATION_MS    10000  // 10 seconds

/**
 * @brief Interval (ms) between automatic watering cycles.
 */
#define AUTO_WATERING_INTERVAL_MS    (15 * 60 * 1000)  // 15 minutes

// =========================
// MAIN LOOP CONFIGURATION
// =========================

/**
 * @brief Delay (ms) at the end of each loop() iteration.
 */
#define LOOP_DELAY_MS    300

#endif // SETTINGS_H

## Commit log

2026-03-16 Add board pinout image
2026-03-16 Write demo code to blink led
2026-03-16 Move led pin define
2026-03-16 Add a screenshot of arduino settings for board.
2026-06-07 Read moisture sensor value. Move wifi credentials into a new "user settings" file.
2026-06-07 Control relay
2026-06-18 Add hardware documentation and 3d plan files
    [PumpSupport.stl, RelaySupport.stl, WateringSystem.3mf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]
2026-06-24 Reorganize pumping code;
2026-06-28 Create a sensor class.
2026-06-28 Create a VoltageSensor class
2026-07-10 Control wifi led
2026-07-11 Add a c_cpp_properties.json file with path to arduino folder
2026-07-11 Read push button input
2026-07-11 Print button press event and change loop period to 100ms
2026-07-11 Adjust leds and wifi reco
2026-07-11 Simplify pump code.
2026-07-12 Change led pin
2026-07-12 Update soil moisture sensor code.
2026-07-13 Don't enable pump when moisture sensor seems to be out of the dirt
2026-07-13 Only turn on LEDs when button is pressed
2026-07-13 Enable the pump for 10s max every minute. Work on battery voltage measurement.
2026-07-13 print battery voltage
2026-07-13 Signal auto mode on LED 6
2026-07-17 Updte solar voltage input code.?
2026-07-26 Fix logic. Control battery low led based on read voltage.
    [settings.h, system.ino]
2026-08-05 Fix battery low led not verifying button pressed.
    [settings.h, system.ino]
2026-08-10 Add a dedicated battery file. Prevent enabling the pump when battery is low.
    [system.ino]
2026-08-10 Add config for Kicad MCP server.
2026-08-10 Commit PCB design (Kicad) files.
    [WateringSystem_PCB.kicad_pcb, WateringSystem_PCB.kicad_sch]
2026-08-10 Add decoupling capacitors on 5V and 3V3
    [WateringSystem_PCB.kicad_sch]
2026-08-10 Add a "no connect" to moisture sensor connector pin 2.
    [WateringSystem_PCB.kicad_sch]
2026-08-10 Fix errors in pcb design.
    [WateringSystem_PCB.kicad_sch]
2026-08-11 Fix moisture level not correctly evaluated to floating.
    [settings.h]
2026-08-11 Fix leds not taking button press into account.
    [system.ino]
2026-08-22 Set RELAY_PIN to 10
